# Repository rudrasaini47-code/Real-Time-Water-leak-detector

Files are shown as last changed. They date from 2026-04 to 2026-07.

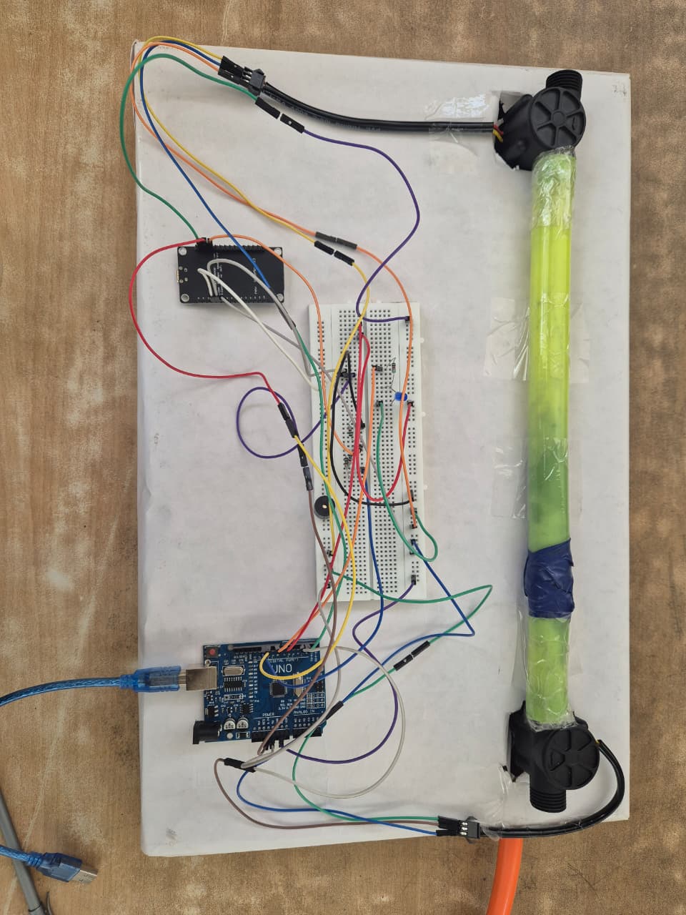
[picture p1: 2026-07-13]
IMAGES/Prototype.png

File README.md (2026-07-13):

# Real Time Water Leak Detector
 
> **Smart water pipeline leak detection system with automatic valve shutoff, real-time web dashboard, and WiFi monitoring — built with Arduino Uno, NodeMCU ESP8266, and YF-S201 flow sensors.**
 
---
 
##  Demo
 
```
Flow IN: 14.20 L/min  |  Flow OUT: 11.60 L/min  |  Diff: 2.60 L/min  →   LEAK DETECTED → True
```
 
Live dashboard updates every 2 seconds. Leak triggers browser notification + sound alert + automatic valve shutoff within 3 seconds of detection.
 
---
 
##  Features
 
- **Real-time flow monitoring** — measures Flow IN and Flow OUT simultaneously using YF-S201 Hall-effect sensors
- **Intelligent leak detection** — compares flow difference mathematically (no moisture sensor needed)
- **False alarm prevention** — requires 3 consecutive seconds of sustained difference before triggering
- **Automatic valve shutoff** — 12V solenoid valve closes instantly when leak is confirmed
- **WiFi dashboard** — live web UI accessible from any browser on the same network
- **Multi-alert system** — in-app toast, browser push notification, and sound alert on leak
- **No cloud needed** — ESP8266 hosts its own API endpoint on local WiFi
- **Works with hotspot** — connect ESP8266 to mobile hotspot for portable use
---
 
##  Hardware Required
 
| Component | Quantity | Notes |
|---|---|---|
| Arduino Uno (R3) | 1 | Any revision |
| NodeMCU v3.0 (ESP8266) | 1 | Has onboard USB — easiest to flash |
| YF-S201 Flow Sensor | 2 | One inlet, one outlet |
| 1kΩ Resistor | 1 | Voltage divider |
| 2kΩ Resistor | 1 | Voltage divider (or 2× 1kΩ in series) |
| Breadboard + Jumper Wires | — | Male-to-male and male-to-female |

##  Wiring
 
### Arduino Uno Pin Connections
| Arduino Pin | Connected To |
|---|---|
| `2` (Digital) | YF-S201 Flow IN signal (yellow wire) |
| `3` (Digital) | YF-S201 Flow OUT signal (yellow wire) |
| `TX` (pin 1) | NodeMCU RX via voltage divider |
| `RX` (pin 0) | NodeMCU TX (direct) |
| `5V` | Both YF-S201 VCC (red wires) + Relay VCC |
| `3.3V` | NodeMCU 3V3 pin |
| `GND` | All component GNDs (shared) |
 
### NodeMCU v3.0 Pin Connections
 
| NodeMCU Pin | Connected To |
|---|---|
| `3V3` | Arduino 3.3V |
| `GND` | Arduino GND (shared) |
| `D9 / RX` | Arduino TX (pin 1) via voltage divider |
| `D10 / TX` | Arduino RX (pin 0) direct |
 
> All other NodeMCU pins are left unconnected.
 
### Voltage Divider (mandatory — protects NodeMCU RX from 5V)
 
```
Arduino TX (pin 1) ──[1kΩ]──┬──── NodeMCU RX (D9)
                             │
                           [2kΩ]
                             │
                            GND
 
Output voltage: 5V × (2kΩ / 3kΩ) = 3.33V ✓
```
 
##  File Structure
 
```
FlowWatch
│
├── arduino_flowwatch.ino     ← Upload to Arduino Uno
├── esp8266_flowwatch.ino     ← Upload to NodeMCU ESP8266
├── flow-monitor.html         ← Open in browser for dashboard
└── README.md
```

## PCB Specifications
 
- **Layers:** 2 (F.Cu / B.Cu)
- **Thickness:** 1.6 mm
- **Mounting:** 4x 2.5mm mounting holes
- **Connectors:** 6x 3.5mm screw terminals (Degson DG250 series)
- **Design tool:** KiCad

## Files
 
- `RealTimeWaterLeak.kicad_sch` — Schematic
- `RealTimeWaterLeak.kicad_pcb` — PCB layout
 
---
 
##  Setup
 
### Step 1 — Configure WiFi credentials
 
Open `esp8266_flowwatch.ino` and set your WiFi name and password:
 
```cpp
const char* WIFI_SSID     = "Your_WiFi_Or_Hotspot_Name";
const char* WIFI_PASSWORD = "yourpassword";
```
 
> **Note:** ESP8266 only supports 2.4GHz WiFi. If using Android hotspot, force it to 2.4GHz in hotspot settings.

### Step 2 — Upload Arduino code
 
1. **Disconnect NodeMCU TX/RX wires** from Arduino pins 0 and 1
2. Connect Arduino to laptop via USB
3. Arduino IDE → Tools → Board → **Arduino Uno**
4. Upload `arduino_flowwatch.ino`
5. Open Serial Monitor at **9600 baud** — verify output looks like:
```
   IN:0.00,OUT:0.00,LEAK:0,VALVE:1,DIFF:0.00
```
6. Close Serial Monitor → reconnect NodeMCU TX/RX wires
### Step 3 — Upload ESP8266 code
 
1. Connect **NodeMCU** to laptop via USB (Arduino disconnected)
2. Arduino IDE → Tools → Board → **NodeMCU 1.0 (ESP-12E Module)**
3. Tools → Upload Speed → **115200**
4. Upload `esp8266_flowwatch.ino`
5. LED blinks while connecting to WiFi, goes solid when connected
### Step 4 — Find NodeMCU IP address
 
- **Mobile hotspot:** Check connected devices list in your hotspot settings — look for "espressif"
- **Home router:** Open router admin page → connected devices → find "ESP8266"
- **Verify:** Open `http://<ESP_IP>/` in browser — status page should load with live readings
### Step 5 — Open dashboard
 
1. Open `flow-monitor.html` in Chrome or Edge
2. Enter API URL: `http://<ESP_IP>/api/flow-data`
3. Click **▶ Start Polling**
4. Allow browser notification permission
5. All 5 cards update in real time 
---
 
##  How Leak Detection Works
 
```
Every 1 second:
  flowDiff = flowIn − flowOut
 
  if flowDiff < 2.0  →  Normal, reset counter
  if flowDiff ≥ 2.0  →  Increment confirmation counter
  if counter ≥ 3     →  LEAK CONFIRMED
                           → dashboard alerts fire
                           → browser notification sent
                           → sound alert plays
 
Press reset button (D6) after fixing leak → valve reopens
```
 
The 3-second confirmation window prevents false alarms from sensor jitter when taps open/close suddenly.
 
---
 
##  API Reference
 
The NodeMCU hosts a JSON REST API on port 80.
 
### `GET /api/flow-data`
 
```json
{
  "flow_in": 14.20,
  "flow_out": 11.60,
  "flow_diff": 2.60,
  "leak": 1,
  "valve_open": 0,
  "uptime_s": 3420,
  "has_data": true,
  "stale": false
}
```
 
| Field | Type | Description |
|---|---|---|
| `flow_in` | float | Inlet flow rate in L/min |
| `flow_out` | float | Outlet flow rate in L/min |
| `flow_diff` | float | Difference (flow_in − flow_out) |
| `leak` | int | 0 = normal, 1 = leak detected |
| `uptime_s` | int | ESP8266 uptime in seconds |
| `has_data` | bool | False until first Arduino reading received |
| `stale` | bool | True if no update received in 10+ seconds |
 
### `GET /`
 
Human-readable status page. Auto-refreshes every 2 seconds.
 
---
 
##  Configuration
 
Adjustable constants in `arduino_flowwatch.ino`:
 
```cpp
const float LEAK_THRESHOLD    = 2.0;   // L/min difference to trigger alert
const int   CONFIRM_COUNT     = 3;     // Consecutive detections before confirming
const float CALIBRATION_FACTOR = 7.5;  // YF-S201: pulses/sec per L/min
const unsigned long SEND_INTERVAL = 2000;  // How often to send data to ESP (ms)
```
 
**Tuning tips:**
- Too many false alarms → increase `LEAK_THRESHOLD` to 3.0 or `CONFIRM_COUNT` to 5
- Missing real leaks → decrease `LEAK_THRESHOLD` to 1.0 or 1.5
- Readings seem off → adjust `CALIBRATION_FACTOR` (valid range: 4.5 – 8.5 for YF-S201)
---
 
##  Important Notes
 
### Upload rule
**Always disconnect NodeMCU TX/RX wires before uploading to Arduino.** Arduino Uno shares its only serial port (pins 0/1) with USB. Reconnect after upload.
 
### Power
- Arduino powered by USB (any 5V phone charger or laptop)
- NodeMCU powered from Arduino 3.3V pin — **do not connect NodeMCU USB and Arduino 3.3V simultaneously**

### Network
The device running the dashboard must be on the **same WiFi/hotspot** as the NodeMCU. The NodeMCU IP may change after power cycles — set a static DHCP lease in your router to fix it permanently.
 
---
 
##  Troubleshooting
 
| Problem | Cause | Fix |
|---|---|---|
| Dashboard shows all zeros | Serial Monitor open | Close Serial Monitor — it conflicts with ESP communication |
| Dashboard shows all zeros | Two power sources on NodeMCU | Remove USB from NodeMCU — power only from Arduino 3.3V |
| Flow always reads 0.00 | Wrong interrupt pins | YF-S201 signal must go to pin **2** and pin **3** on Uno |
| ESP not connecting to WiFi | Wrong credentials or 5GHz | Double-check SSID/password. Force Android hotspot to 2.4GHz |
| ESP broadcasting own WiFi | Failed to join network | Same as above — ESP falls back to AP mode on failure |
| Upload fails | NodeMCU TX/RX still connected | Disconnect pins 0 and 1 from NodeMCU before uploading |
| False leak alerts | Sensor jitter | Increase `LEAK_THRESHOLD` to 3.0 or `CONFIRM_COUNT` to 5 |
| Random ESP resets | Power instability | Add 100µF capacitor between NodeMCU 3V3 and GND |
 
---

## Built With
 
- **Arduino Uno** — sensor reading, flow calculation, valve control
- **NodeMCU ESP8266** — WiFi connectivity, JSON API server
- **YF-S201** — Hall-effect pulse flow sensors
- **Arduino IDE** — firmware development
- **Chart.js** — real-time flow history chart in dashboard
- **Vanilla HTML/CSS/JS** — zero-dependency web dashboard
---

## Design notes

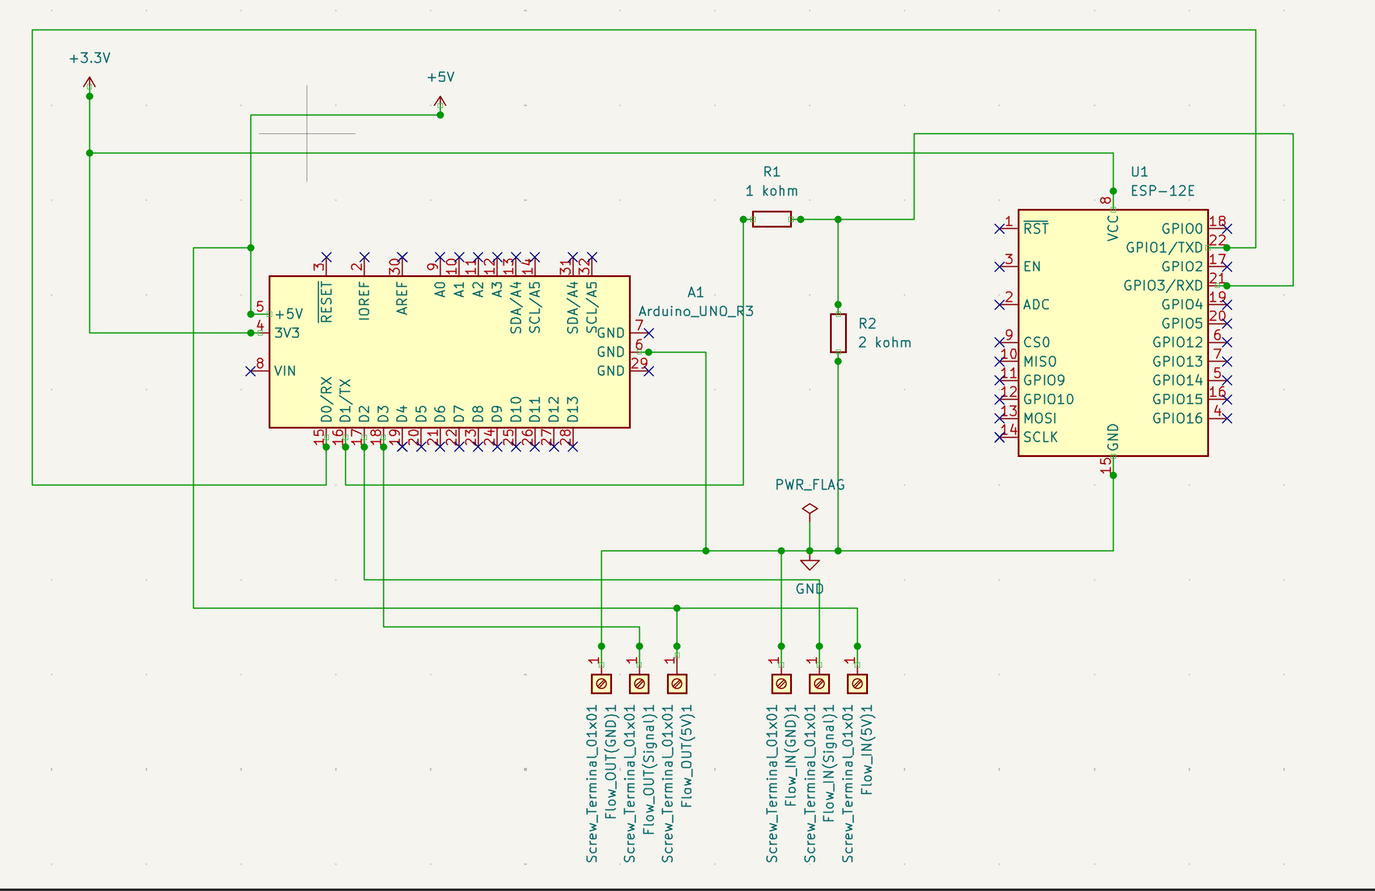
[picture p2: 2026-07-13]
IMAGES/PCB_Schematic.png

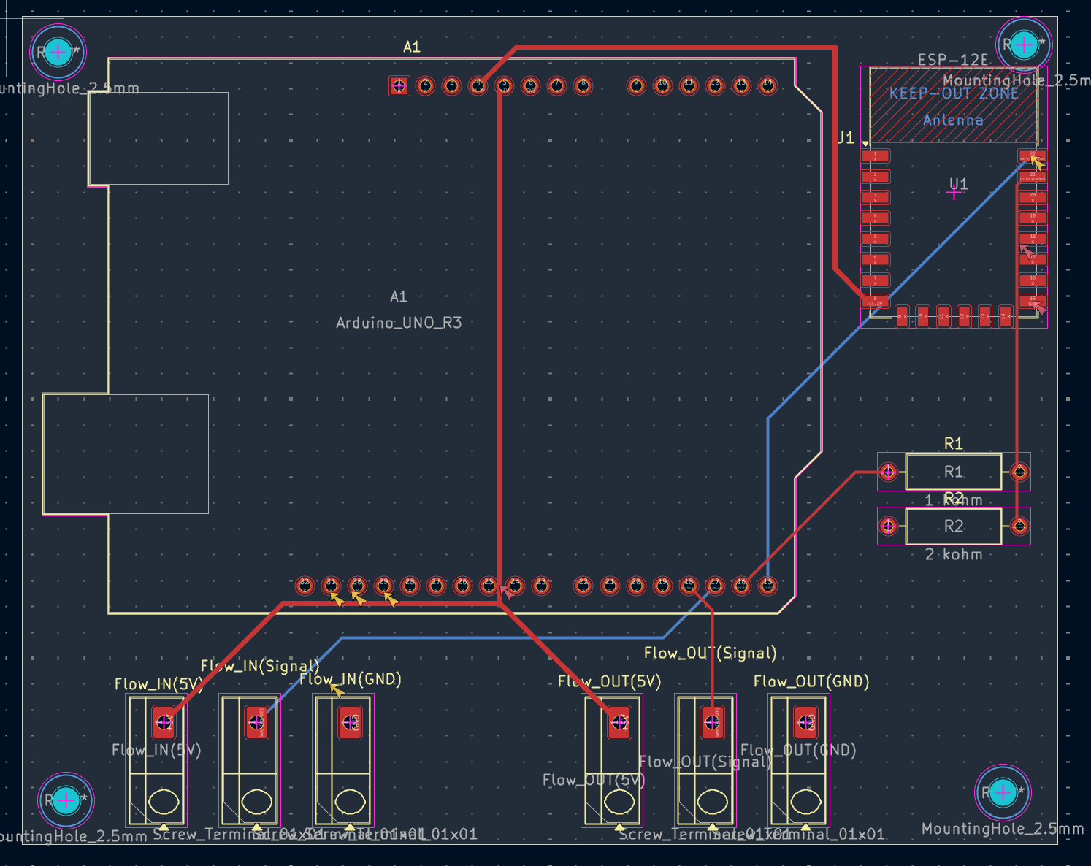
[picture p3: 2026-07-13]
IMAGES/PCB_Layout.png

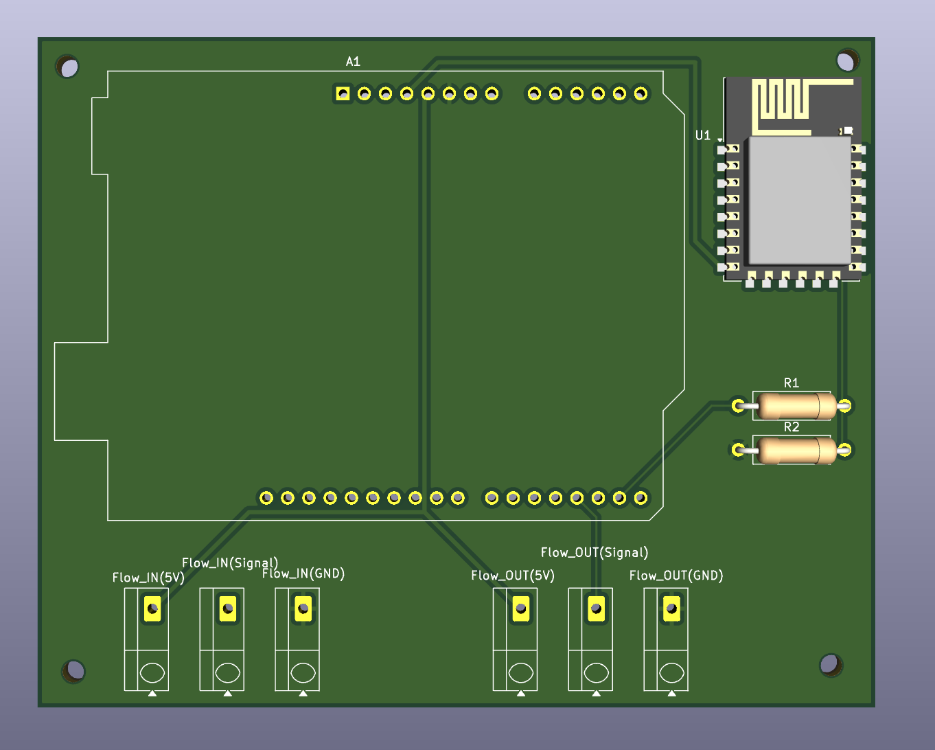
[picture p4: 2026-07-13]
IMAGES/PCB_FrontView.png

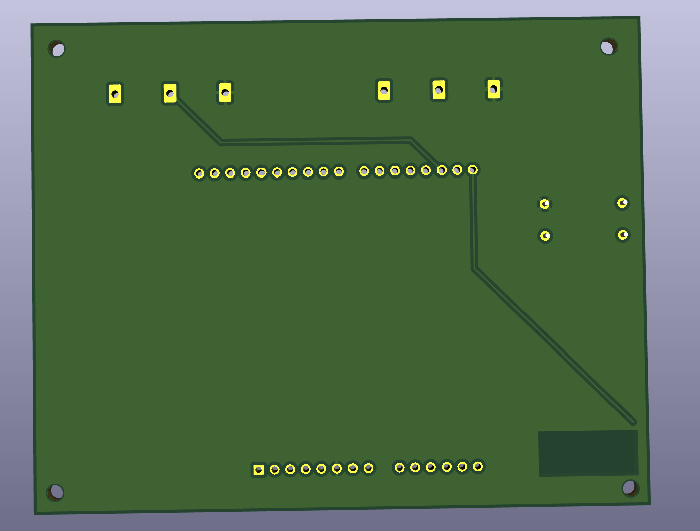
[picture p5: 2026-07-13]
IMAGES/PCB_BackView.png

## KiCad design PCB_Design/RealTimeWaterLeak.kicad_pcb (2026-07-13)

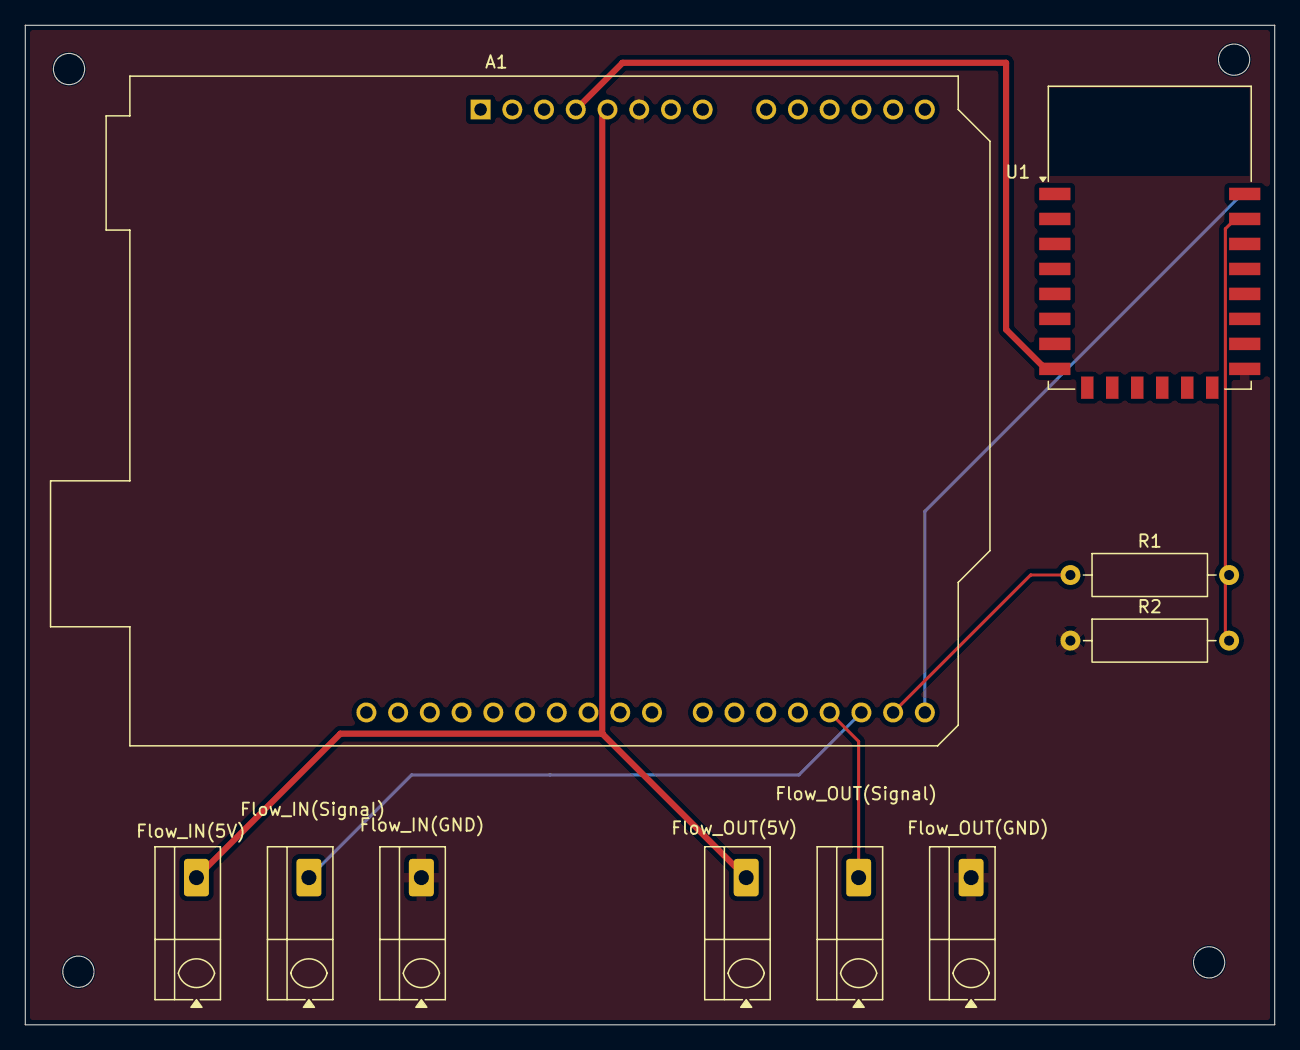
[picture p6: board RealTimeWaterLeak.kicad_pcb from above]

Board: 2 copper layers, 100.0 x 80.0 mm, 10 parts (0 on the bottom side), 8 nets.

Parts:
A1: Arduino_UNO_R3
Flow_IN(5V): Screw_Terminal_01x01; TerminalBlock_Degson_DG250-3.5-01P_1x01_P3.50mm_45Degree
Flow_IN(GND): Screw_Terminal_01x01; TerminalBlock_Degson_DG250-3.5-01P_1x01_P3.50mm_45Degree
Flow_IN(Signal): Screw_Terminal_01x01; TerminalBlock_Degson_DG250-3.5-01P_1x01_P3.50mm_45Degree
Flow_OUT(5V): Screw_Terminal_01x01; TerminalBlock_Degson_DG250-3.5-01P_1x01_P3.50mm_45Degree
Flow_OUT(GND): Screw_Terminal_01x01; TerminalBlock_Degson_DG250-3.5-01P_1x01_P3.50mm_45Degree
Flow_OUT(Signal): Screw_Terminal_01x01; TerminalBlock_Degson_DG250-3.5-01P_1x01_P3.50mm_45Degree
R1: 1 kohm; R_Axial_DIN0309_L9.0mm_D3.2mm_P12.70mm_Horizontal
R2: 2 kohm; R_Axial_DIN0309_L9.0mm_D3.2mm_P12.70mm_Horizontal
U1: ESP-12E

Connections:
+3.3V: A1.4 (3V3), U1.8 (VCC)
+5V: A1.5 (+5V), Flow_IN(5V).1 (Pin_1_1), Flow_OUT(5V).1 (Pin_1_1)
GND: A1.6 (GND), Flow_IN(GND).1 (Pin_1_1), Flow_OUT(GND).1 (Pin_1_1), R2.1, U1.15 (GND)
unnamed: A1.15 (D0/RX), U1.22 (GPIO1/TXD)
unnamed: A1.16 (D1/TX), R1.1
unnamed: A1.17 (D2), Flow_IN(Signal).1 (Pin_1_1)
unnamed: A1.18 (D3), Flow_OUT(Signal).1 (Pin_1_1)
unnamed: R1.2, R2.2, U1.21 (GPIO3/RXD)

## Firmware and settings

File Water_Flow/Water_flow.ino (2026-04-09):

#include <SoftwareSerial.h>

// ── PIN DEFINITIONS ────────────────────────────────────────
#define FLOW_IN_PIN    2      
#define FLOW_OUT_PIN   3      
#define VALVE_PIN      5      
#define RESET_BTN_PIN  6      
#define BUZZER_PIN     7    
#define LED_PIN        8    

// NEW: Use pins 10 and 11 for the ESP8266
SoftwareSerial espSerial(10, 11); // RX, TX

// ... (Keep all your existing variables: flowIn, flowOut, etc.) ...

void triggerAlert(bool active) {
  if (active) {
    digitalWrite(LED_PIN, HIGH);      // LED on solid
    digitalWrite(BUZZER_PIN, HIGH);   // buzzer on
  } else {
    digitalWrite(LED_PIN, LOW);
    digitalWrite(BUZZER_PIN, LOW);
  }
}

const float LEAK_THRESHOLD     = 2.0;   // L/min difference

// How many consecutive detections before triggering alert
// Prevents false alarms from sensor jitter
const int   CONFIRM_COUNT      = 3;     // 3 × 1 second = 3s sustained difference

// ── YF-S201 CALIBRATION ────────────────────────────────────
// 7.5 pulses/sec = 1 L/min  (YF-S201 datasheet)
// Adjust if your readings seem off (try 4.5–8.5 range)
const float CALIBRATION_FACTOR = 7.5;

// ── TIMING ─────────────────────────────────────────────────
const unsigned long MEASURE_INTERVAL = 1000;   // Calculate flow every 1s
const unsigned long SEND_INTERVAL    = 2000;   // Send to ESP every 2s
const unsigned long DEBOUNCE_MS      = 50;     // Button debounce

// ── PULSE COUNTERS ─────────────────────────────────────────
volatile unsigned long pulseCountIn  = 0;
volatile unsigned long pulseCountOut = 0;

// ── FLOW VALUES ────────────────────────────────────────────
float flowIn        = 0.0;    // Current L/min
float flowOut       = 0.0;    // Current L/min
float flowDiff      = 0.0;    // flowIn - flowOut
float totalIn       = 0.0;    // Total litres since boot
float totalOut      = 0.0;    // Total litres since boot

// ── LEAK & VALVE STATE ─────────────────────────────────────
int   leakDetected   = 0;     // 0=normal, 1=leak
bool  valveOpen      = true;  // true=open, false=closed
int   confirmCounter = 0;     // Consecutive leak detections
bool  leakAcknowledged = false; // Stays true until manual reset

// ── TIMERS ─────────────────────────────────────────────────
unsigned long lastMeasureTime  = 0;
unsigned long lastSendTime     = 0;
unsigned long lastBtnTime      = 0;

// ── INTERRUPT SERVICE ROUTINES ─────────────────────────────
void  countPulseIn()  { pulseCountIn++;  }
void  countPulseOut() { pulseCountOut++; }



void setup() {
  Serial.begin(9600);    // For your computer
  espSerial.begin(9600); // For the ESP8266

  // ... (Keep your pinMode and interrupt settings) ...
  
  pinMode(FLOW_IN_PIN, INPUT_PULLUP);
  pinMode(FLOW_OUT_PIN, INPUT_PULLUP);
  pinMode(BUZZER_PIN, OUTPUT);
  pinMode(LED_PIN, OUTPUT);
  pinMode(VALVE_PIN, OUTPUT);
  digitalWrite(VALVE_PIN, LOW); 
  pinMode(RESET_BTN_PIN, INPUT_PULLUP);

  attachInterrupt(digitalPinToInterrupt(FLOW_IN_PIN), countPulseIn, FALLING);
  attachInterrupt(digitalPinToInterrupt(FLOW_OUT_PIN), countPulseOut, FALLING);

  Serial.println("System Ready - Monitoring Serial Monitor and ESP8266");
}

void loop() {
  unsigned long now = millis();

  if (now - lastMeasureTime >= MEASURE_INTERVAL) {
    lastMeasureTime = now;
    calculateFlow();
    checkForLeak();
  }

  if (now - lastSendTime >= SEND_INTERVAL) {
    lastSendTime = now;
    sendToESP();
  }

  checkResetButton();
}

void calculateFlow() {
  // Read and reset pulse counters atomically
  noInterrupts();
  unsigned long pIn  = pulseCountIn;
  unsigned long pOut = pulseCountOut;
  pulseCountIn  = 0;
  pulseCountOut = 0;
  interrupts();

  // Convert pulses → L/min
  // Measured over 1 second: pulses/sec ÷ 7.5 = L/min
  flowIn  = (float)pIn  / CALIBRATION_FACTOR;
  flowOut = (float)pOut / CALIBRATION_FACTOR;

  // Flow difference — the core leak detection metric
  flowDiff = flowIn - flowOut;

  // Accumulate totals (L/min over 1 second = L/60 per measurement)
  totalIn  += flowIn  / 60.0;
  totalOut += flowOut / 60.0;
}


// ═══════════════════════════════════════════════════════════
//  LEAK DETECTION & VALVE CONTROL
// ═══════════════════════════════════════════════════════════
void checkForLeak() {

  // ── Case 1: No flow at all — skip detection ──────────────
  // Avoid false alarms when system is idle
  if (flowIn < 0.5 && flowOut < 0.5) {
    confirmCounter = 0;
    // Only clear leak if it wasn't manually acknowledged
    if (!leakAcknowledged) {
      leakDetected = 0;
    }
    return;
  }

  // ── Case 2: Flow difference exceeds threshold ─────────────
  if (flowDiff > LEAK_THRESHOLD) {
    confirmCounter++;

    if (confirmCounter >= CONFIRM_COUNT && !leakAcknowledged) {
      // Confirmed leak — close the valve
      leakDetected     = 1;
      leakAcknowledged = true;
      closeValve();
      triggerAlert(true);  
    }
  } else {
    // Difference is within normal range — reset counter
    confirmCounter = 0;

    // Only clear the leak flag if not yet acknowledged
    // (keeps valve closed and alert active until manual reset)
    if (!leakAcknowledged) {
      leakDetected = 0;
    }
  }
}


// ═══════════════════════════════════════════════════════════
//  VALVE CONTROL
// ═══════════════════════════════════════════════════════════
void closeValve() {
  digitalWrite(VALVE_PIN, HIGH);   // HIGH = relay ON = valve CLOSED
  valveOpen = false;
}

void openValve() {
  digitalWrite(VALVE_PIN, LOW);    // LOW = relay OFF = valve OPEN
  valveOpen = true;
}


// ═══════════════════════════════════════════════════════════
//  MANUAL RESET BUTTON
//  Press to reopen valve after fixing the leak
// ═══════════════════════════════════════════════════════════
void checkResetButton() {
  unsigned long now = millis();

  // Debounce
  if (now - lastBtnTime < DEBOUNCE_MS) return;

  // Button pressed (pulled LOW)
  if (digitalRead(RESET_BTN_PIN) == LOW) {
    lastBtnTime = now;

    if (leakAcknowledged) {
      // Reset everything
      leakDetected     = 0;
      leakAcknowledged = false;
      confirmCounter   = 0;
      triggerAlert(false); 
      openValve();

      // Notify ESP of manual reset
      Serial.println("FLOWWATCH_RESET");
    }
  }
}

// Update this function to send to espSerial
void sendToESP() {
  // We send to BOTH so you can see it on your screen and the website
  String data = "IN:" + String(flowIn, 2) + 
                ",OUT:" + String(flowOut, 2) + 
                ",LEAK:" + String(leakDetected) + 
                ",VALVE:" + String(valveOpen ? 1 : 0) + 
                ",DIFF:" + String(flowDiff, 2);

  Serial.println(data);    // See it on your PC
  espSerial.println(data); // Send it to the Website
}

// ... (Keep the rest of your helper functions: calculateFlow, checkResetButton, etc.) ...

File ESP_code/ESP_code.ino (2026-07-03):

#include <ESP8266WiFi.h>
#include <ESP8266WebServer.h>

// ── CONFIGURATION ──────────────────────────────────────────
const char* WIFI_SSID     = "Your_WIFI_Name"; 
const char* WIFI_PASSWORD = "Your_WIFI_Password"; 

ESP8266WebServer server(80);

// Data Variables
float  flowIn = 0.0, flowOut = 0.0, flowDiff = 0.0;
int    leak = 0, valveOpen = 1;
bool   hasData = false;
String rawString = "No data yet"; // For debugging on the website
unsigned long lastUpdate = 0;
String inputBuffer = "";

void setup() {
  Serial.begin(9600); // Must match Arduino Baud Rate
  
  pinMode(LED_BUILTIN, OUTPUT);
  digitalWrite(LED_BUILTIN, HIGH); // LED OFF

  WiFi.mode(WIFI_STA);
  WiFi.begin(WIFI_SSID, WIFI_PASSWORD);

  // FIX: Connection Loop
  int attempts = 0;
  while (WiFi.status() != WL_CONNECTED && attempts < 40) {
    delay(500);
    digitalWrite(LED_BUILTIN, !digitalRead(LED_BUILTIN));
    attempts++;
  }

  if (WiFi.status() == WL_CONNECTED) {
    digitalWrite(LED_BUILTIN, LOW); // Solid ON when connected
  }

  server.on("/", handleRoot);
  server.on("/api/flow-data", handleFlowData);
  server.begin();
}

void loop() {
  server.handleClient();
  readSerial();
}

// ── API ENDPOINT ───────────────────────────────────────────
void handleFlowData() {
  server.sendHeader("Access-Control-Allow-Origin", "*");
  String json = "{";
  json += "\"flow_in\":"   + String(flowIn, 2)   + ",";
  json += "\"flow_out\":"  + String(flowOut, 2)  + ",";
  json += "\"flow_diff\":" + String(flowDiff, 2) + ",";
  json += "\"leak\":"      + String(leak)         + ",";
  json += "\"valve_open\":" + String(valveOpen)   + ",";
  json += "\"raw\":\""     + rawString            + "\""; 
  json += "}";
  server.send(200, "application/json", json);
}

// ── WEBSITE HTML ───────────────────────────────────────────
void handleRoot() {
  String ip = WiFi.localIP().toString();
  String html = "<!DOCTYPE html><html><head>";
  html += "<meta name='viewport' content='width=device-width, initial-scale=1'>";
  html += "<style>body{background:#080d14;color:#c8dff0;font-family:monospace;padding:20px;text-align:center}";
  html += ".card{background:#121a24;border:1px solid #1a2d44;padding:20px;border-radius:10px;display:inline-block;min-width:280px}";
  html += "h2{color:#00e5ff} .val{font-size:1.8em;color:#00e676;font-weight:bold}";
  html += ".debug{margin-top:20px;font-size:0.8em;color:#566d8a;word-break:break-all}</style></head><body>";

  html += "<div class='card'><h2>FlowWatch v2</h2>";
  html += "<p>Flow IN<br><span id='fin' class='val'>0.00</span> L/min</p>";
  html += "<p>Flow OUT<br><span id='fout' class='val'>0.00</span> L/min</p>";
  html += "<hr style='border-color:#1a2d44'>";
  html += "<p id='lstatus'>Status: Initializing...</p></div>";
  
  // Debug text to see the raw serial string
  html += "<div class='debug'>Raw Serial: <span id='raw'>...</span></div>";

  html += "<script>";
  html += "function update(){ fetch('/api/flow-data').then(r=>r.json()).then(d=>{";
  html += "document.getElementById('fin').innerText=d.flow_in.toFixed(2);";
  html += "document.getElementById('fout').innerText=d.flow_out.toFixed(2);";
  html += "document.getElementById('raw').innerText=d.raw;";
  html += "document.getElementById('lstatus').innerHTML=d.leak==1?'<b style=\"color:#ff1744\">⚠ LEAK DETECTED</b>':'<b>System OK</b>';";
  html += "}).catch(e=>document.getElementById('lstatus').innerText='Fetch Error: '+e); }";
  html += "setInterval(update,1000);</script></body></html>";

  server.send(200, "text/html", html);
}

// ── SERIAL PARSING ─────────────────────────────────────────
void readSerial() {
  while (Serial.available()) {
    char c = (char)Serial.read();
    if (c == '\n') {
      inputBuffer.trim();
      if (inputBuffer.length() > 0) {
        rawString = inputBuffer; // Save for debug
        parseLine(inputBuffer);
      }
      inputBuffer = "";
    } else if (c != '\r') {
      inputBuffer += c;
    }
  }
}

void parseLine(String line) {
  // Must match Arduino: "IN:0.00,OUT:0.00,LEAK:0,VALVE:1,DIFF:0.00"
  if (line.indexOf("IN:") < 0) return;

  flowIn    = extractFloat(line, "IN:",    ",OUT:");
  flowOut   = extractFloat(line, "OUT:",   ",LEAK:");
  leak      = (int)extractFloat(line, "LEAK:",  ",VALVE:");
  valveOpen = (int)extractFloat(line, "VALVE:", ",DIFF:");
  
  // FIX: Look for the rest of the string after DIFF:
  int diffIndex = line.indexOf("DIFF:");
  if (diffIndex >= 0) {
    flowDiff = line.substring(diffIndex + 5).toFloat();
  }

  hasData = true;
  lastUpdate = millis();
}

float extractFloat(String src, String startMark, String endMark) {
  int s = src.indexOf(startMark);
  if (s < 0) return 0.0;
  s += startMark.length();
  int e = src.indexOf(endMark, s);
  if (e < 0) return 0.0;
  return src.substring(s, e).toFloat();
}
